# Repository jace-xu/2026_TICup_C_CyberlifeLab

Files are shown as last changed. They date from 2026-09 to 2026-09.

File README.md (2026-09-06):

# 2026 TI Cup — Wireless Digital Key System

A digital key and smart lock prototype developed for Problem C of the 2026 TI Cup Undergraduate Electronic Design Contest (Guangdong Division). The system combines UWB wireless communication with LiDAR localization to identify an authorized key, track its position, and trigger welcome alerts, automatic unlocking, and locking when the key leaves the designated area.

## Highlights

- **Key identification:** An STM32F103-based wireless key transmits a configurable 4-bit ID for matching against the lock's configured ID.
- **Position tracking:** A Raspberry Pi 5 running ROS 2 processes RPLIDAR C1 scans using background modeling, target extraction, and clustering, then sends distance and bearing to an STM32H723 over USB serial.
- **Sensor fusion:** Supports UWB-only and UWB/LiDAR modes, with coordinate alignment, outlier rejection, and Kalman filtering to reduce positioning drift.
- **Embedded control:** STM32H723 firmware handles UWB UART and Raspberry Pi USB CDC communication, matches key IDs, and drives proximity-based status logic, the serial display, RGB LEDs, and buzzer.
- **Integrated hardware:** A display, lights, and buzzer provide status feedback, with a custom 3D-printed enclosure and mounting structure.

**Tech stack:** STM32 · Embedded C · STM32 HAL · Keil MDK · Raspberry Pi 5 · ROS 2 · Python · UWB · LiDAR · Kalman Filter · SolidWorks

## Prototypes

<p align="center">
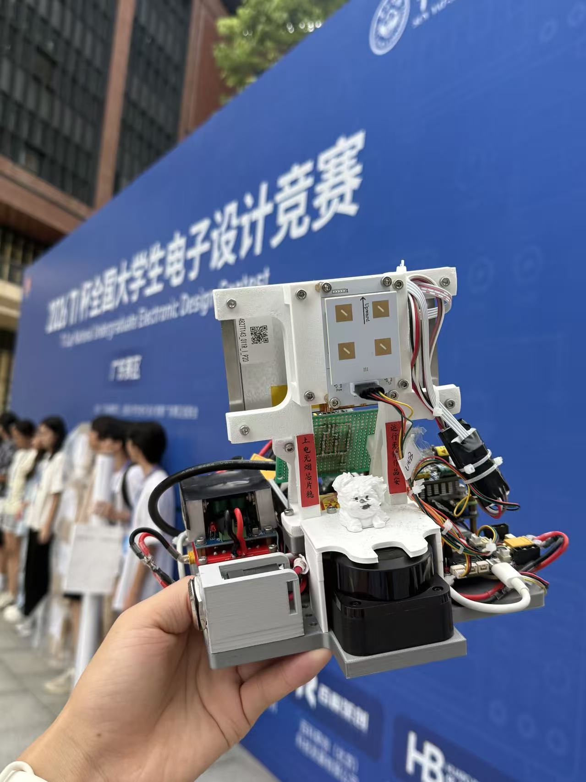
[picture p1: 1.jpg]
Smart lock prototype at the competition venue
  
</p>

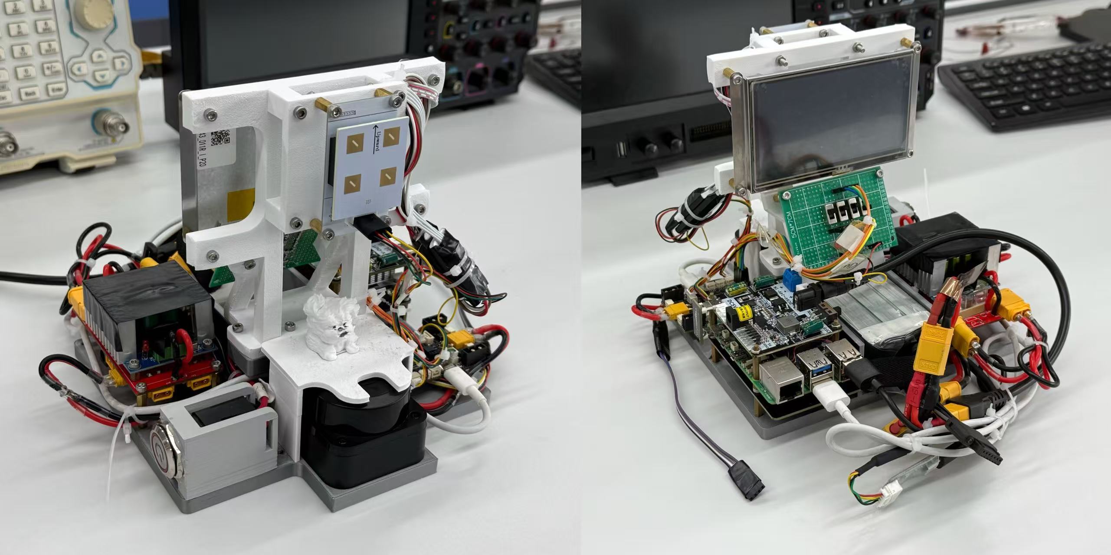
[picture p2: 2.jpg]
Front and rear views of the smart lock


### Digital Key

<p align="center">
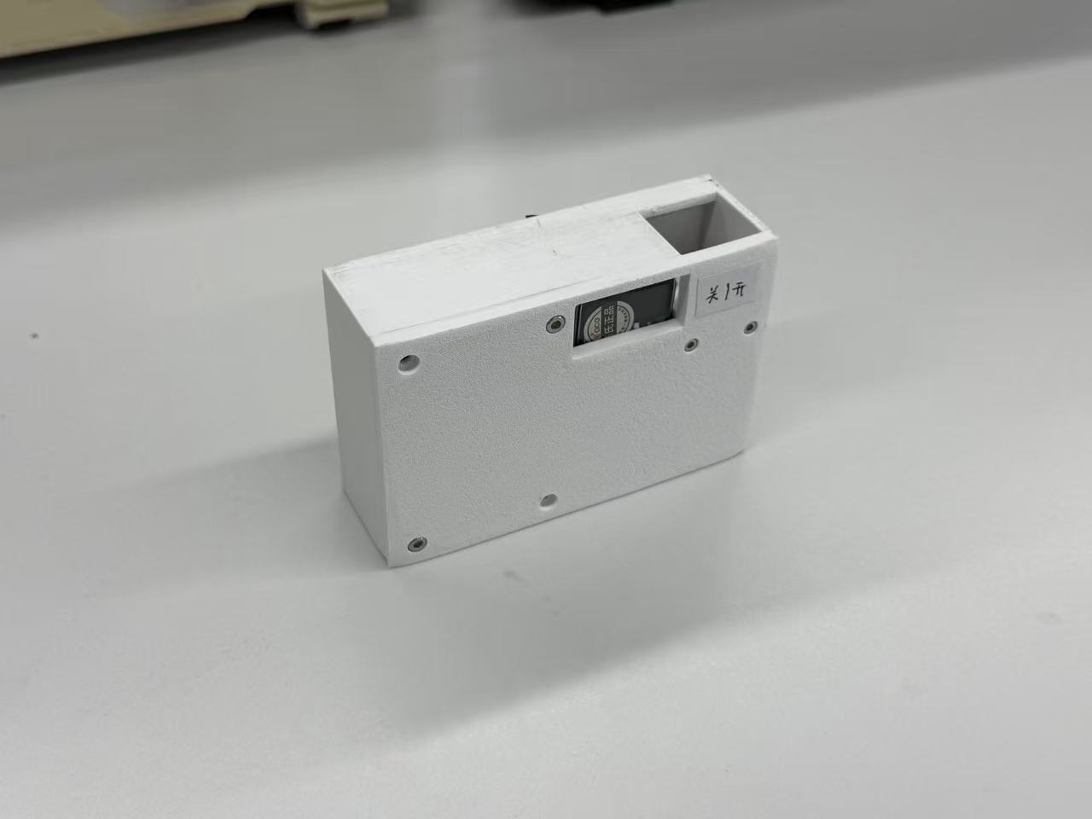
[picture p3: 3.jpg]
Wireless digital key prototype
  
</p>

## Our Team

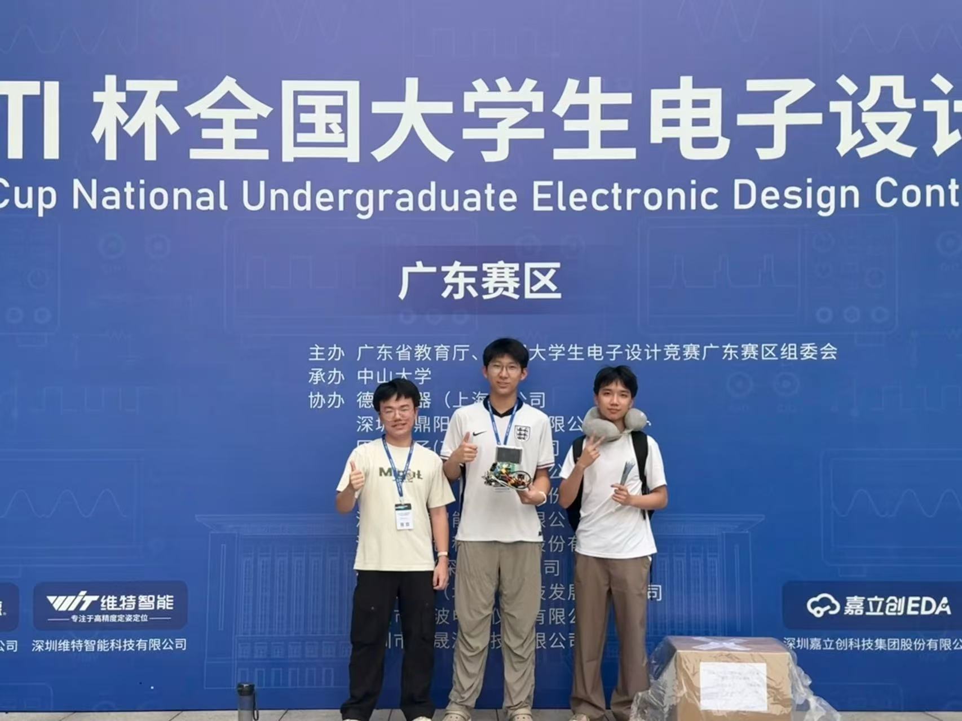
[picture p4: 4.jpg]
Our team at the competition


## Repository

- [`Electronics_STM32H7/`](Electronics_STM32H7/) — STM32H723 smart lock firmware, including peripheral drivers, communication, and status control, with STM32CubeMX and Keil MDK project files.

- [`Pi5_lidar/`](Pi5_lidar/) — ROS 2 workspace for LiDAR localization and serial communication.
- [`Structure/`](Structure/) — SolidWorks models and STEP files for the mechanical assembly.
- [`Report.pdf`](Report.pdf) — Project report with system design and test results (Chinese).

## License

Original project code is licensed under the [GNU General Public License v3.0](LICENSE) (SPDX: `GPL-3.0-only`). Third-party components retain their respective licenses and copyright notices.

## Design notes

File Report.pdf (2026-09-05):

# 2026 年全国大学生电子设计竞赛 广东赛区竞赛

## 基于无线通信的数字钥匙实验系统系统（C 题）

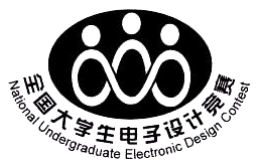
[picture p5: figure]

# 2026 年 8 月 1 日

I

摘 要

针对数字钥匙系统在身份认证、复杂环境稳定定位方面的要求，本设计研制

了一套基于无线通信的数字钥匙实验系统。系统由数字钥匙和智能门锁两部分组

成。数字钥匙端以 STM32F103C8T6 为控制核心，由开关、电池、UWB 无线模块和

降压模块，实现一键启动及 4 位身份 ID 持续发送。智能门锁端由 UWB 基站、激

光雷达、树莓派、STM32H723、串口屏、四位拨码开关和声光装置组成。UWB 基

站接收钥匙 ID 并输出距离和方位角；树莓派完成雷达背景建模、目标提取、聚

类跟踪和位置计算，通过 USB 虚拟串口将结果发送至 STM32H723。系统支持纯 UWB

和 UWB/激光雷达融合两种模式。融合模式下，H723 对两路观测进行坐标统一、

时间匹配和异常值剔除，并通过卡尔曼滤波获得更准确的钥匙位置，解决了纯

UWB 定位的漂移问题。控制系统比较接收 ID 与拨码设定 ID，根据径向距离完成

感应区、迎宾区和开锁区判决，并显示身份、位置、区域和门锁状态，控制灯光、

蜂鸣器及开闭锁指示灯。测试结果表明，系统可实现身份验证、迎宾提示、自动

开锁、离区闭锁和 ID 修改识别，满足题目要求。

关键词：数字钥匙；UWB；激光雷达；卡尔曼滤波；多传感器融合

目录

## 一、系统方案

1、主控制器件的论证与选择

2、定位方案的论证与选择
3、电源方案的论证与选择

## 二、系统理论分析与计算

1、UWB 身份认证与定位原理

2、激光雷达目标定位

3、UWB 与激光雷达融合定位

## 三、电路与程序设计

1、电路设计

2、程序设计

## 四、测试方案与测试结果

1、测试方案

2、测试条件与仪器

3、测试结果及分析

## 五、参考文献

## 基于无线通信的数字钥匙实验系统（C 题）

## 一、系统方案

本系统由数字钥匙和智能门锁两部分组成，主要包括数字钥匙控制模块、UWB 无线

通信模块、激光雷达定位模块、主控制与数据融合模块、人机交互与执行模块以及电源

模块。数字钥匙持续发送身份 ID 信息，智能门锁通过 UWB 和激光雷达获取数字钥匙的

位置，并完成身份验证、定位模式切换、区域判决、状态显示及开闭锁控制。下面分别

对系统中的主要方案进行论证与选择。

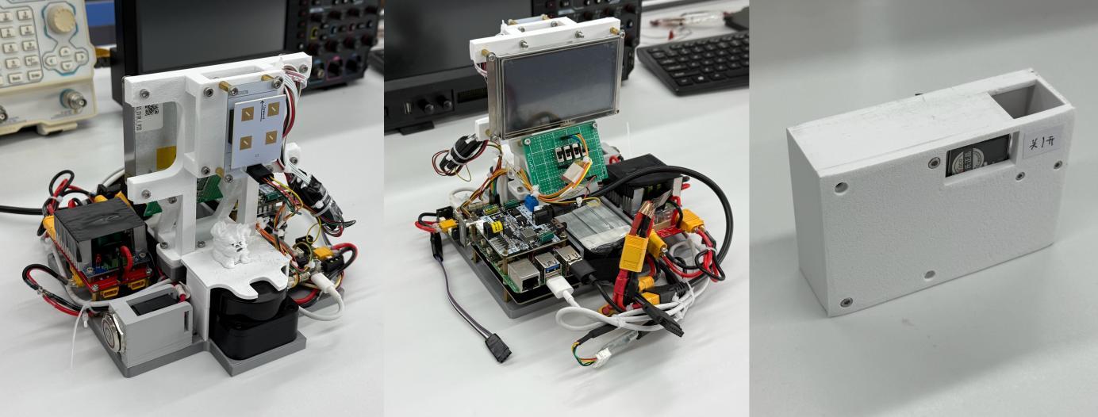
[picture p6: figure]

图 1.1 团队设计的基于无线通信的数字钥匙实验系统，自左到右分别为智能门锁正面，

智能门锁背面，数字钥匙

1、主控制器件的论证与选择

方案一：单片机独立控制。

单片机实时性好、接口丰富，可完成数据接收和设备控制，但运算及存储能力有限，

难以实时处理激光雷达点云数据，因此不适合作为整体控制方案。

方案二：树莓派独立控制。

树莓派运算能力强，可实现雷达驱动和定位算法，但 GPIO 实时性和抗干扰能力较弱，

直接控制门锁、声光装置等设备，可靠性不足。

方案三：树莓派与 STM32H723 协同控制。

树莓派负责雷达数据处理和位置计算，并将结果发送至 STM32H723；STM32H723 负责

接收 UWB 数据，完成数据融合、身份验证、区域判决及门锁和声光控制。数字钥匙采用

STM32F103C8T6 发送身份 ID。

综合比较，本系统选择方案三。该方案兼顾树莓派的运算能力和单片机的实时控制

性能，可提高系统的实时性、可靠性和可维护性。

2、定位方案的论证与选择

方案一：采用纯 UWB 定位。

UWB 可同时传输身份 ID 并输出距离和方位角，具有结构简单、数据链路短等优点。

但室内反射和多径效应容易造成测量波动，影响区域边界判决的稳定性。

方案二：采用纯激光雷达定位。

激光雷达测距和测角精度较高，不受无线电多径影响。树莓派可通过背景差分、目

标聚类和连续跟踪提取钥匙靶标，但雷达无法独立识别身份 ID，且容易受到靶标姿态、

反射特性和短时遮挡影响。

方案三：UWB 与激光雷达融合定位。

该方案使用卡尔曼滤波融合 UWB 的身份与位置数据和激光雷达的几何定位结果。当

UWB 受到多径干扰时提高雷达权重，当雷达短时丢点时利用 UWB 维持定位，从而提高测

量精度和稳定性。

综合比较，本系统采用双模式方案：纯 UWB 模式用于独立定位和备用运行，UWB/激

光雷达融合模式作为主要工作模式。

3、电源方案的论证与选择

方案一：分散式供电。

各模块分别使用对应电压的电池，或由一块 24V 电池配合多个独立 DC-DC 模块供电。

该方案配置灵活、便于单独调试，但电池和稳压模块数量较多，存在接线复杂、成本增

加、体积较大及电磁干扰难以统一控制等问题，不利于系统集成。

方案二：集中式稳压分电板供电。

智能门锁端采用一块 24V 电池，将输入保护、降压和多路分配电路集中在自制 PCB

分电板上，输出 24V、12V 和 5V 等电压；数字钥匙端采用一块 12V 电池，经板载降压模

块供电。该方案接线清晰、结构紧凑，便于统一完成滤波、接地、散热和故障排查。

综合比较，本系统选择方案二，以提高供电系统的集成度、稳定性和可靠性。 二、系统理论分析与计算

1、UWB 身份认证与定位原理

本系统采用 ALX-AOA-FIT 模块，工作于单基站、单信标模式。基站基于单芯片 UWB

方案，片上集成 32 位 MCU，通过 4 天线阵列实现 AOA 测量；信标安装于数字钥匙端，持

续发送 UWB 信号。

UWB 测距基于双边双向飞行时间原理，基站与信标之间交替收发时间戳，消除两

Δ =

4 − 1 − 3 − 2

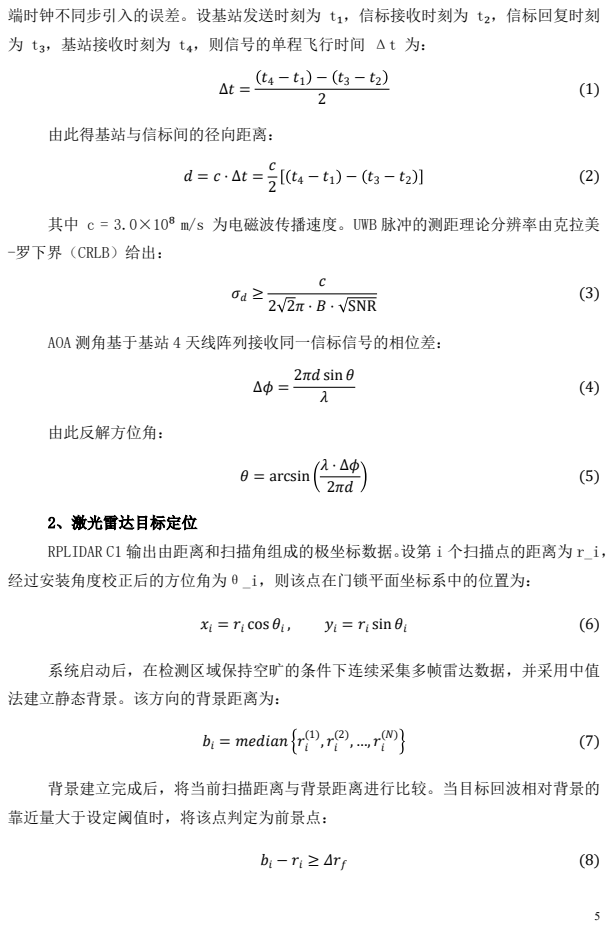
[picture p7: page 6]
端时钟不同步引入的误差。设基站发送时刻为 t₁，信标接收时刻为 t₂，信标回复时刻; 为 t₃，基站接收时刻为 t₄，则信号的单程飞行时间 Δt 为： 2; 由此得基站与信标间的径向距离：  =  ⋅ Δ =;  2 2 ⋅  ⋅ SNR; 2 sin  ; 由此反解方位角：;  = arcsin;  =  cos ; ,  =  sin 

其中 c = 3.0×10⁸ m/s 为电磁波传播速度。UWB 脉冲的测距理论分辨率由克拉美

-罗下界（CRLB）给出：

AOA 测角基于基站 4 天线阵列接收同一信标信号的相位差：

2、激光雷达目标定位
RPLIDAR C1 输出由距离和扫描角组成的极坐标数据。设第 i 个扫描点的距离为 r_i，
经过安装角度校正后的方位角为θ_i，则该点在门锁平面坐标系中的位置为：

系统启动后，在检测区域保持空旷的条件下连续采集多帧雷达数据，并采用中值
法建立静态背景。该方向的背景距离为：

背景建立完成后，将当前扫描距离与背景距离进行比较。当目标回波相对背景的
靠近量大于设定阈值时，将该点判定为前景点：

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

## 三、电路与程序设计

1、电路设计

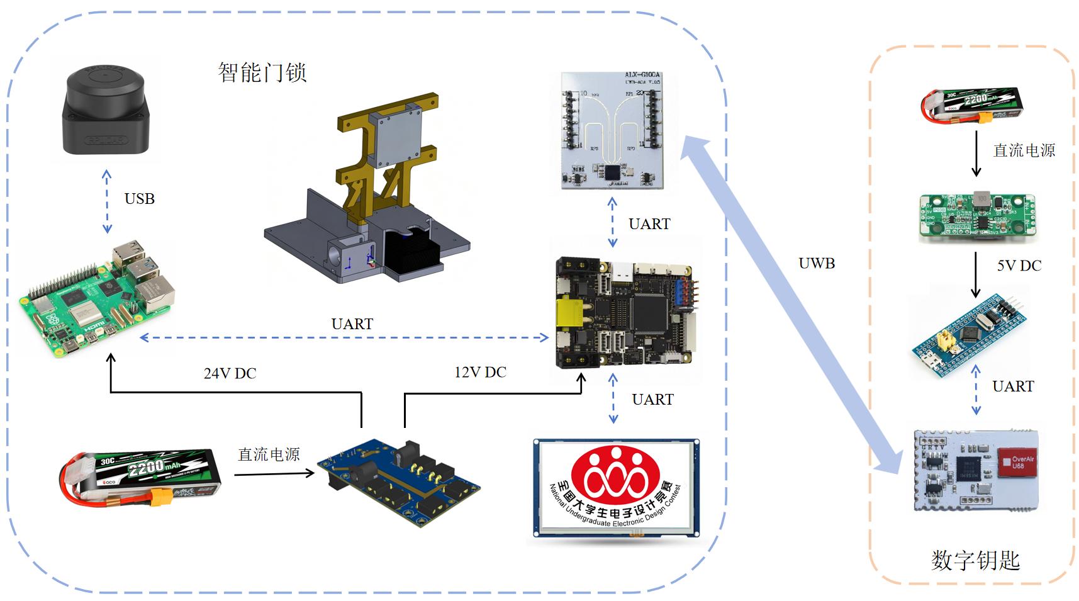
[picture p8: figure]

图 3.1 系统电路架构图

1.1 数字钥匙子系统的电路设计

数字钥匙子系统由 STM32F103C8T6、DW3000 PDOA 从机模块和电源电路组成。系统上

电后，单片机配置 UWB 模块并写入身份 ID，由模块周期性广播定位信标，供门锁端解算

钥匙的距离和方位角。12 V 锂电池经降压后为各模块供电，保证系统稳定运行。

1.2 智能门锁子系统的电路设计

本系统采用树莓派与 STM32H7 组成双主控架构。24 V 电源经降压后为两块主控板供

电，树莓派通过 USB 为激光雷达供电。树莓派负责雷达数据处理、人员检测和定位计算，

并通过 USB 虚拟串口与 STM32H7 通信；STM32H7 负责接收定位结果、执行实时控制以及

管理各类外设。

UWB 模块用于获取数字钥匙的身份 ID、距离和方位角，激光雷达用于辅助人员检测

和定位。STM32H7 将钥匙 ID 与拨码开关设定值进行比对，并根据身份和位置控制门锁状

态；串口屏显示身份及定位信息，开锁和闭锁 LED 用于指示门锁状态。系统采用默认闭

锁原则，仅在身份验证通过且钥匙进入开锁区域时执行开锁。

2、程序设计
2.1 数字钥匙子系统的程序设计

数字钥匙端采用 STM32F103C8T6 作为控制器，外部开关直接控制数字钥匙的电源通

断。开关闭合后，控制器和 UWB 无线模块上电，程序依次完成系统时钟、GPIO、串口及

无线模块初始化，并装载数字钥匙预设的 4 位身份 ID。

初始化完成后，程序立即进入循环发送状态。STM32F103C8T6 将身份 ID 按照规定的

数据格式进行封装，并控制 UWB 无线模块按照固定时间间隔持续发送。门锁端 UWB 基站

接收到无线信号后，可获得数字钥匙的标签 ID 以及相应的位置观测数据。

在运行过程中，程序持续检查 UWB 无线模块的工作状态。若某次数据发送未正常完

成，则清除当前发送状态，并在下一发送周期重新传输，从而提高无线通信的连续性和

可靠性。只要电源开关保持闭合，数字钥匙就会持续发送身份 ID；用户断开电源开关后，

数字钥匙停止工作。
2.2 智能门锁子系统的程序设计

2.2.1 树莓派程序设计

树莓派运行 Ubuntu 24.04 和 ROS 2 Jazzy 系统。程序启动后首先检查激光雷达和

STM32H723 的串口设备是否连接正常，随后启动激光雷达驱动、数字钥匙定位节点和串

口通信节点。

定位节点启动后的前两秒保持检测区域空旷，连续采集多帧雷达数据，并计算各扫

描方向的中值，从而建立静态背景。背景建立完成后，程序持续订阅激光雷达扫描数据，

只保留智能门锁正前方±47°范围内的有效回波。

对于每帧雷达数据，程序首先完成安装角度校正和距离范围筛选，再通过背景差分

提取新进入检测区域的前景点。随后根据相邻点之间的空间距离和角度间隔进行聚类，

并依据数字钥匙定位靶标的尺寸筛除人体、支架等不符合要求的点簇。当检测区域内存

在多个候选目标时，程序选择距离智能门锁最近的有效目标。关于筛选目标的原理，在

前文理论分析处已经得到计算。程序根据目标中心坐标计算数字钥匙相对于门锁圆柱体

边界的径向距离和方位角，并将检测标志、径向距离和方位角封装为固定长度的数据帧，

通过 USB 虚拟串口发送至 STM32H723。

2.2.2 单片机程序设计

STM32H723 是智能门锁的主控制器，主要负责 UWB 和雷达数据接收、工作模式切换、

身份验证、卡尔曼融合、区域判决以及显示和执行器控制。

系统上电后，STM32H723 完成 GPIO、UART、USB 虚拟串口、定时器、SPI 和 PWM 等外

设初始化。UWB 基站通过 UART 发送数字钥匙 ID、距离和方位角，树莓派通过 USB 虚拟

串口发送雷达检测标志、距离和方位角。单片机对接收到的数据进行格式检查，数据错

误或长时间未更新时，将对应观测标记为无效。

程序周期性读取四位拨码开关，并将接收 ID 与设定 ID 进行比较。不一致时，系统

保持闭锁并显示验证失败；一致时，根据模式切换按键选择纯 UWB 模式或融合定位模式。

纯 UWB 模式直接使用 UWB 输出的距离和方位角。融合模式首先将 UWB 和雷达数据转

换到统一坐标系，剔除异常观测，再利用卡尔曼滤波获得融合位置。当某一路数据暂时

失效时，系统使用另一路有效数据继续定位；两路数据均无效时，系统输出未检测状态

并保持闭锁。

身份验证和定位均有效时，单片机根据最终距离判断数字钥匙位于感应区、迎宾区

或开锁区，并控制串口屏、灯光、蜂鸣器以及开闭锁指示灯。程序采用连续帧确认和滞

回判决，防止距离在 1 m 和 2 m 边界附近波动时门锁状态反复切换。

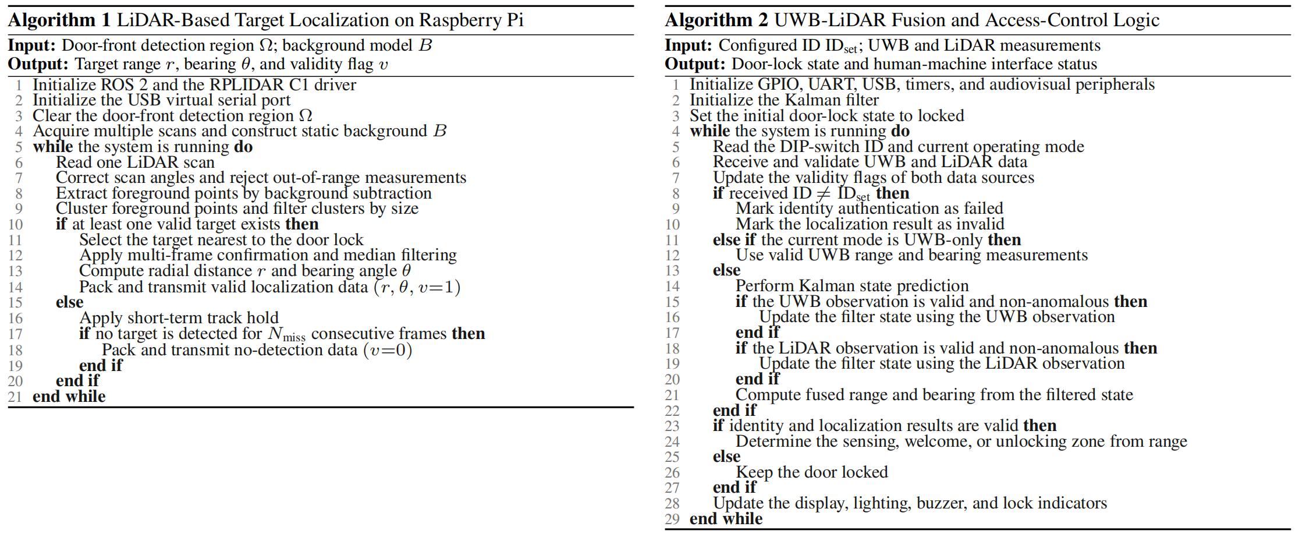
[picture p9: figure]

图 3.2 树莓派和单片机程序的伪代码

## 四、测试方案与测试结果

1、测试方案

在 0.5 m、1.5 m 和 2.5 m 三个距离下，分别设置−40°、−20°、0°、+20°和+40°

五个方位角，共 15 个测试点，每点重复测量 20 次。同步记录 UWB、激光雷达和融合定

位输出的距离及角度，并计算平均误差、均方根误差和最大误差。此外，在 1 m 开锁边

界和 2 m 迎宾边界进行进入、离开测试，验证系统的区域判定性能。

2、测试条件与仪器

测试在室内开阔、无遮挡环境下进行，各定位模块位置保持固定。使用激光测距仪

或钢卷尺标定实际距离，使用角度尺和地面标线确定方位角。主要仪器包括 UWB 模块、

二维激光雷达、数字钥匙、主控板、稳压电源和上位机。

3、测试结果及分析

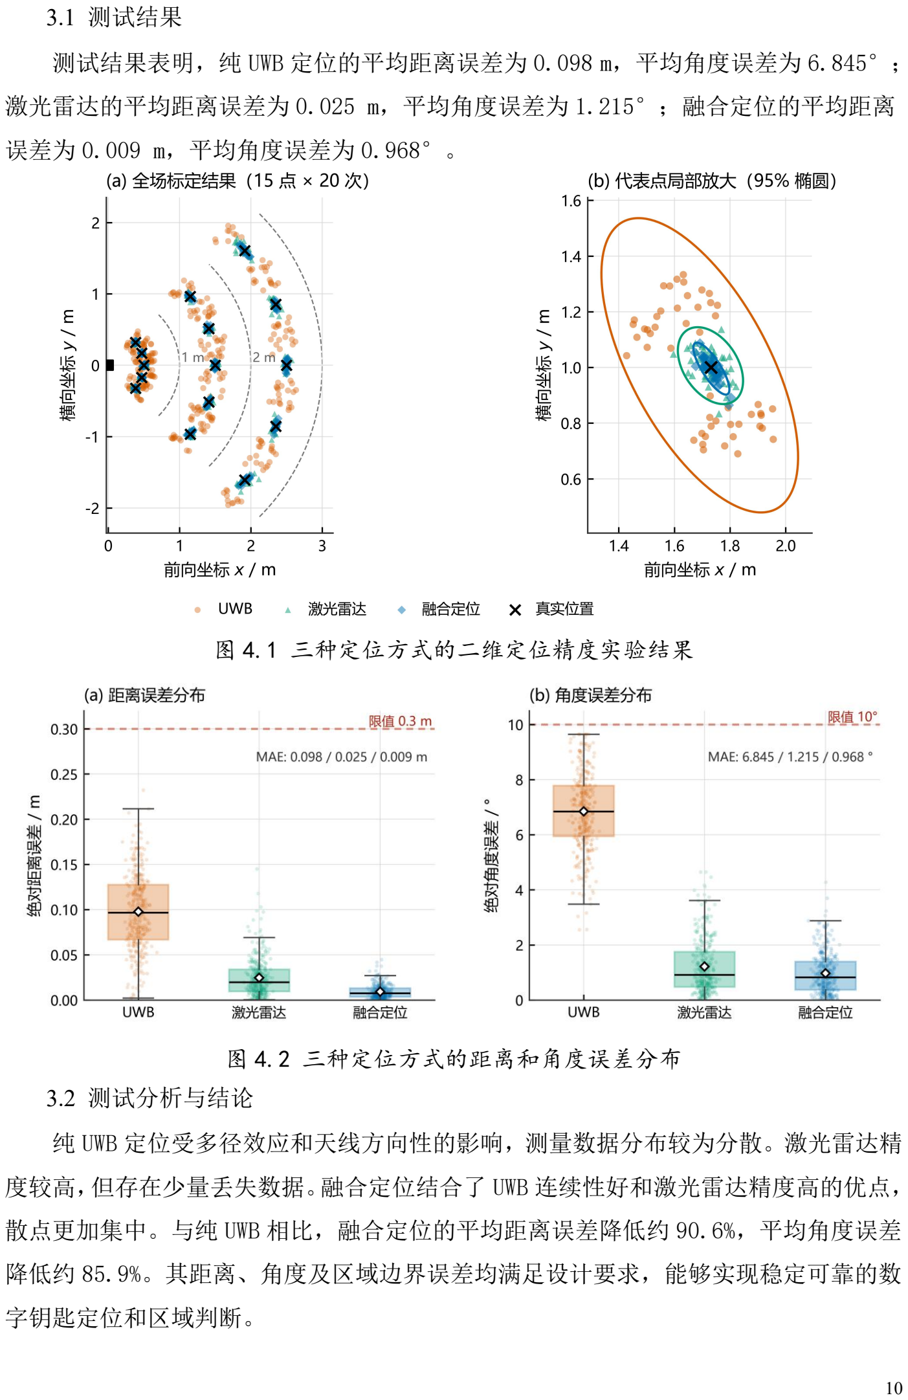
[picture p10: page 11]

3.1 测试结果

测试结果表明，纯 UWB 定位的平均距离误差为 0.098 m，平均角度误差为 6.845°；

激光雷达的平均距离误差为 0.025 m，平均角度误差为 1.215°；融合定位的平均距离

误差为 0.009 m，平均角度误差为 0.968°。

图 4.1 三种定位方式的二维定位精度实验结果

图 4.2 三种定位方式的距离和角度误差分布
3.2 测试分析与结论

纯 UWB 定位受多径效应和天线方向性的影响，测量数据分布较为分散。激光雷达精

度较高，但存在少量丢失数据。融合定位结合了 UWB 连续性好和激光雷达精度高的优点，

散点更加集中。与纯 UWB 相比，融合定位的平均距离误差降低约 90.6%，平均角度误差

降低约 85.9%。其距离、角度及区域边界误差均满足设计要求，能够实现稳定可靠的数

字钥匙定位和区域判断。

## 五、参考文献

[1] 柳景斌。室内高精度定位技术总结与展望 [J]. 武汉大学学报 (信息科学版), 2022. DOI:
10.13203/j.whugis20220029. [2] Sang C L, Adams M, Hesse M, et al. Numerical and Experimental Evaluation of Error Estimation

for Two-Way Ranging Methods[J]. Sensors, 2019, 19(3): 616.DOI: 10.3390/s19030616
[3] Wu J, Xiong Y, Li W, et al. Adaptive Kalman Filter-Based UWB Location Tracking with Optimized DS-TWR in Workshop Non-Line-of-Sight Environments[J]. Sensors, 2025, 25(24): 7682. DOI: 10.3390/s25247682
[4] 郑洪江，夏宝华，韩松源，等。数字钥匙非可视测距研究与实现 [J]. 汽车工程，2026, 48 (6):
1294-1303.DOI: 10.19562/j.chinasae.qcgc.2026.06.007
[5] 谭浩强. C 语言程序设计 [M]. 北京：清华大学出版社，2012. [6] Li T, Wang Y, Zhang H. UWB-LiDAR Tightly Coupled Indoor Positioning System for Mobile

Robots[C]//Proceedings of the 2024 6th International Conference on Robotics and Intelligent Systems. New York: ACM, 2024: 127-134. DOI: 10.1145/3711129.3711
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

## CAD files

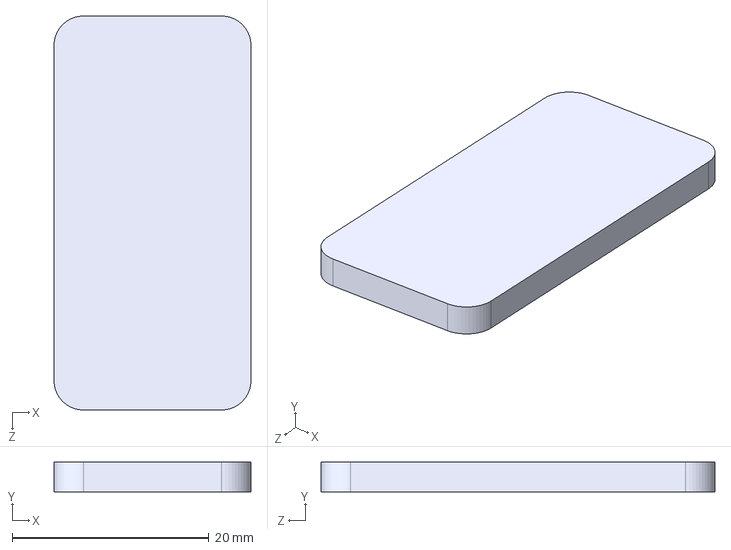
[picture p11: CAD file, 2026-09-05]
Structure/基站建模/杜邦线固定板.STEP
20.0 x 3.00 x 40.0 mm

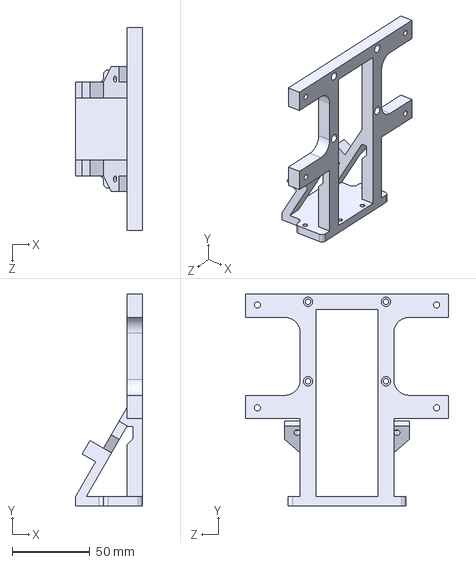
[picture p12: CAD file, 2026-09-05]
Structure/基站建模/基站支架.STEP
43.0 x 136.0 x 130.0 mm

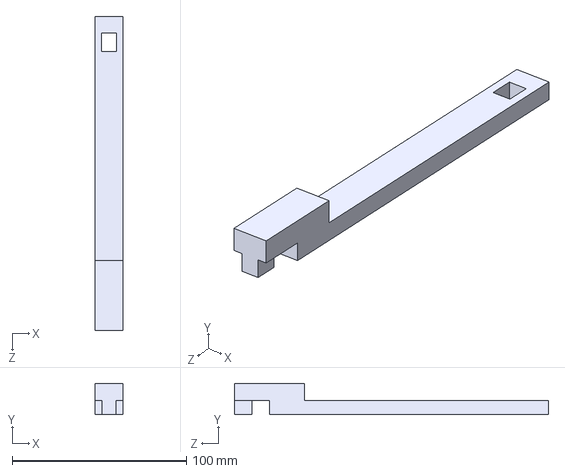
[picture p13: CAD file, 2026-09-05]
Structure/放置基站模具/扩展棍.STEP
16.0 x 18.0 x 180.0 mm

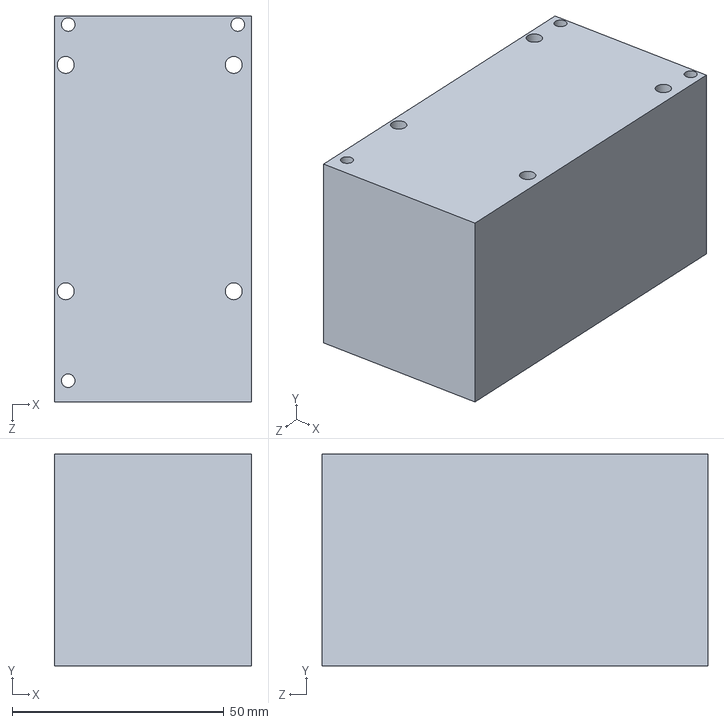
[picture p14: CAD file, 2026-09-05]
Structure/基站建模/降压板.SLDPRT
46.5 x 50.0 x 91.0 mm

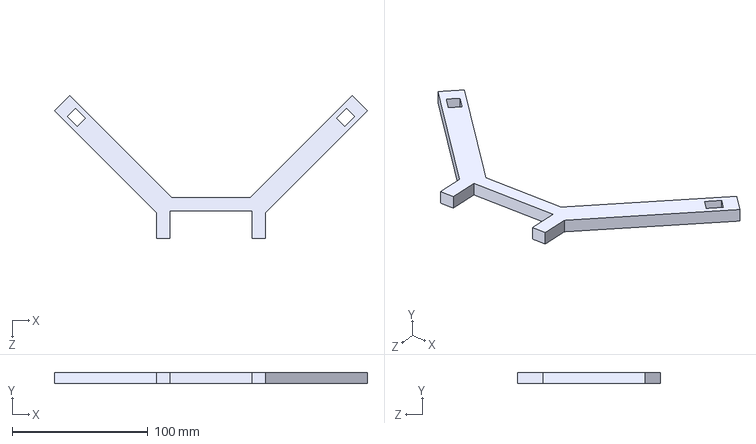
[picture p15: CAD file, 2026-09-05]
Structure/放置基站模具/中心板.STEP
230.5 x 8.00 x 105.3 mm

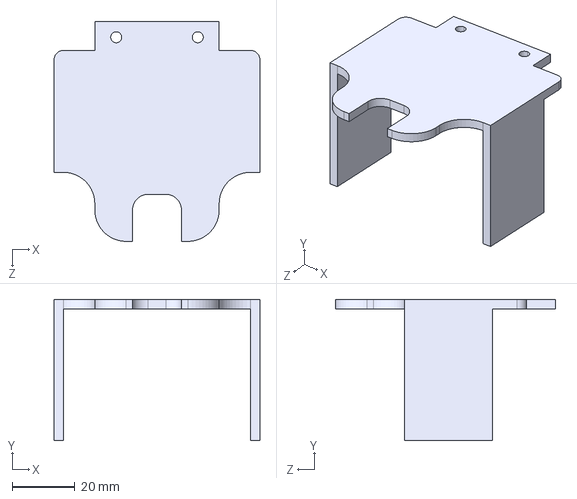
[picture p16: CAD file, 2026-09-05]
Structure/基站建模/雷达罩.STEP
65.6 x 45.0 x 70.0 mm

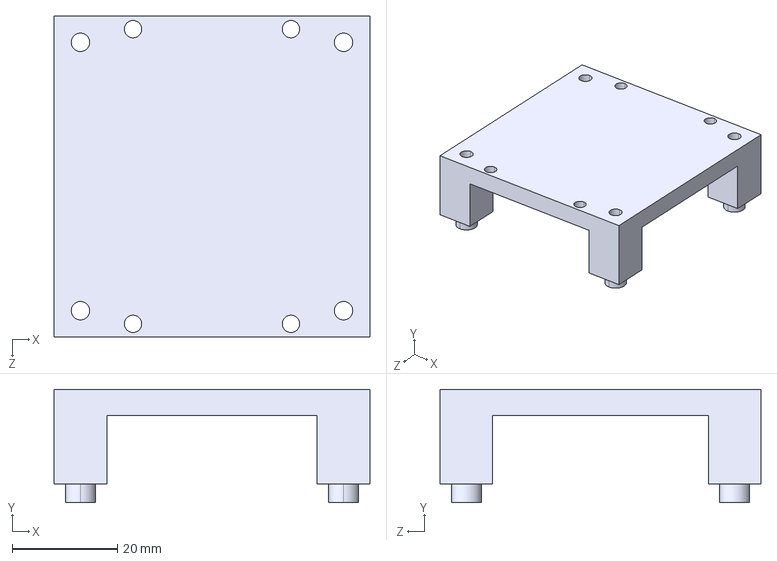
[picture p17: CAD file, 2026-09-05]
Structure/基站建模/基站底板.STEP
60.0 x 21.5 x 61.0 mm

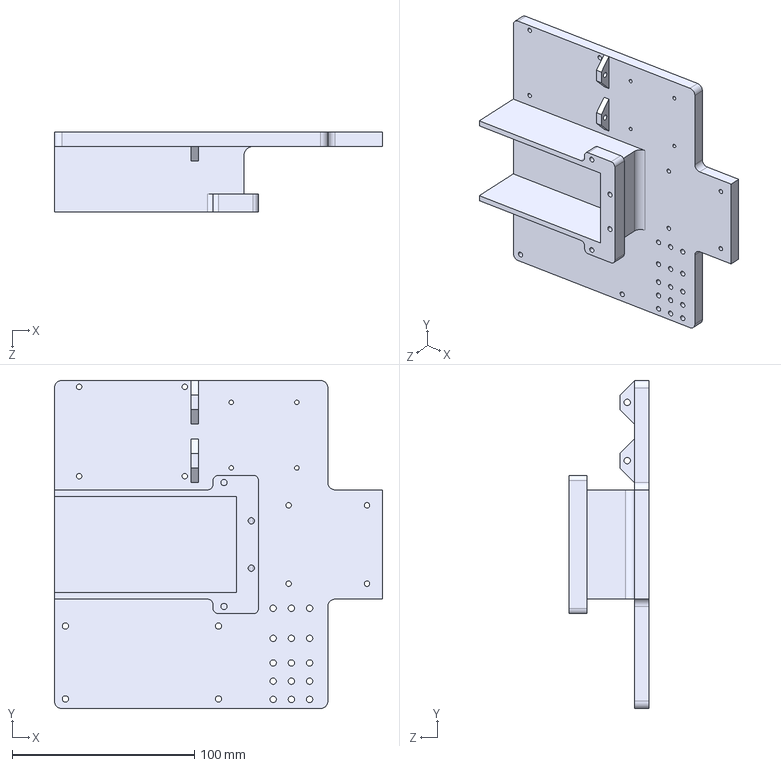
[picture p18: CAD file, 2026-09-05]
Structure/基站建模/雷达底座.STEP
180.0 x 180.0 x 44.0 mm

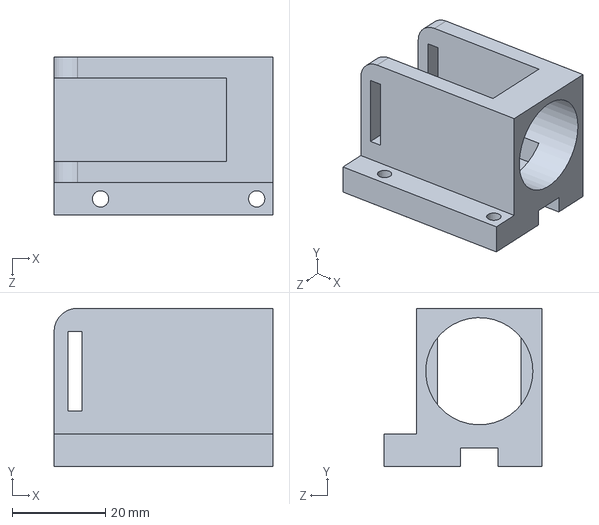
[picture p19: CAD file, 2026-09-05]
Structure/基站建模/开关支架.SLDPRT
47.0 x 34.0 x 34.0 mm

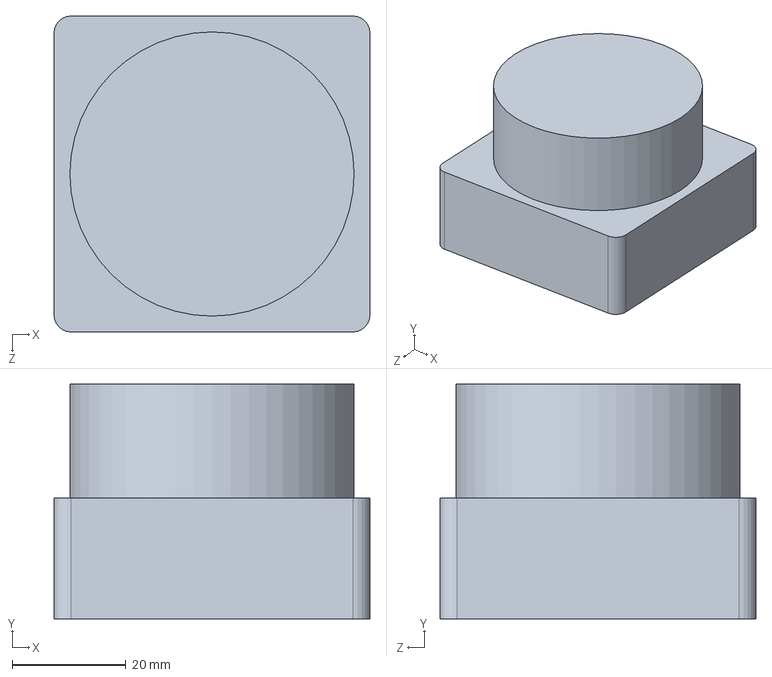
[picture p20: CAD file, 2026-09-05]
Structure/基站建模/c1雷达.SLDPRT
55.6 x 41.3 x 55.6 mm

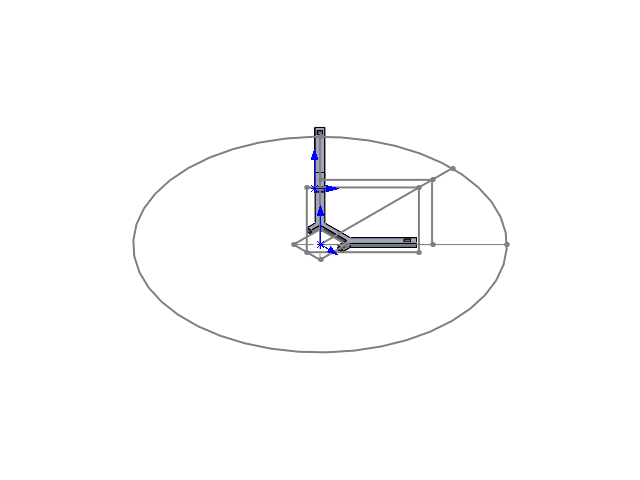
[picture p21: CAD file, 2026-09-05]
Structure/放置基站模具/模具装配体.SLDASM
中心板
扩展棍

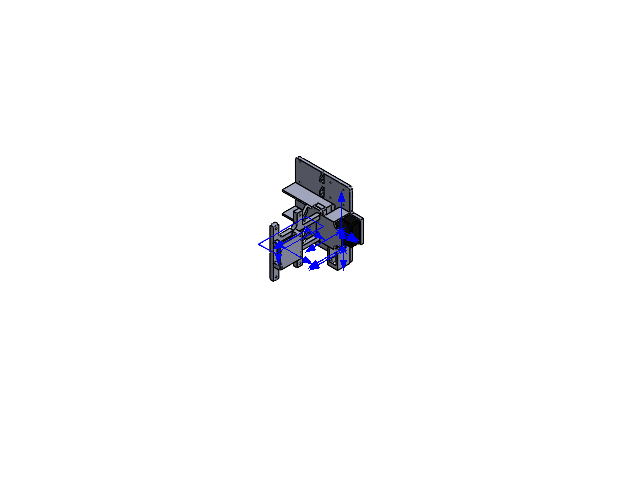
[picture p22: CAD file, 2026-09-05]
Structure/基站建模/基站装配体.SLDASM
雷达底座
c1雷达
基站支架
基站底板
开关支架
雷达罩

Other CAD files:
Structure/基站建模/基站底板.SLDPRT
Structure/基站建模/基站支架.SLDPRT
Structure/基站建模/杜邦线固定板.SLDPRT
Structure/基站建模/雷达底座.SLDPRT
Structure/基站建模/雷达罩.SLDPRT
Structure/放置基站模具/中心板.SLDPRT
Structure/放置基站模具/扩展棍.SLDPRT

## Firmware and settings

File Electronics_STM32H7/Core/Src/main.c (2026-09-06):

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
/* Includes ------------------------------------------------------------------*/
#include "main.h"
#include "spi.h"
#include "tim.h"
#include "usart.h"
#include "usb_device.h"
#include "gpio.h"

/* USER CODE BEGIN Includes */
#include "ws2812.h"
#include "buzzer_driver.h"
/* USER CODE END Includes */


/* USER CODE BEGIN PV */
volatile uint8_t id_receive = 0xFF;
uint8_t id_set = 0;
volatile data_packet_t data_packet = {0};
volatile key_data_t key_data = {0};
volatile uint8_t use_raspi = 1;  /* 1=树莓派数据(USB CDC), 0=UWB模块数据(UART10) */
volatile uint8_t raspi_first_beep = 0;  /* 0=等待首次数据, 1=待蜂鸣, 2=已完成 */
extern uint8_t rx_buffer[];
extern uint8_t rx_buffer2[];

/* WS2812 灯控标志（ISR 写，主循环读） */
extern volatile uint8_t ws2812_update;
extern volatile uint8_t ws2812_r;
extern volatile uint8_t ws2812_g;
extern volatile uint8_t ws2812_b;
extern volatile uint8_t ws2812_last_r;
extern volatile uint8_t ws2812_last_g;
extern volatile uint8_t ws2812_last_b;
/* USER CODE END PV */

void SystemClock_Config(void);
static void MPU_Config(void);
/**
  * @brief  The application entry point.
  * @retval int
  */
int main(void)
{

  /* MPU Configuration--------------------------------------------------------*/
  MPU_Config();

  /* MCU Configuration--------------------------------------------------------*/

  /* Reset of all peripherals, Initializes the Flash interface and the Systick. */
  HAL_Init();

  /* Configure the system clock */
  SystemClock_Config();

  /* Initialize all configured peripherals */
  MX_GPIO_Init();
  MX_TIM1_Init();
  MX_UART7_Init();
  MX_USART10_UART_Init();
  MX_SPI6_Init();
  MX_TIM12_Init();
  MX_USB_DEVICE_Init();
  /* USER CODE BEGIN 2 */
	/* 清空 USART10 RX 残留，避免字节错位导致永久偏移 */
	/* 空闲帧分包接收 UWB 变长数据包（0x2001=37B / 0x2002=16B） */
	HAL_UARTEx_ReceiveToIdle_IT(&huart10, rx_buffer, 64);
	// 开启TIM1 更新中断
	HAL_TIM_Base_Start_IT(&htim1);
  // 开启蜂鸣器
  HAL_TIM_PWM_Start(&htim12, TIM_CHANNEL_2);
  /* 上电测试音：响 300ms 验证蜂鸣器硬件正常 */
  Buzzer_Play(BUZZER_FREQ_C4, 100);
  HAL_Delay(300);
  Buzzer_Stop();
  /* 初始化 flag 引脚：默认树莓派模式 → 高电平 */
  HAL_GPIO_WritePin(flag_GPIO_Port, flag_Pin, GPIO_PIN_SET);
  /* 使能 botton 按键的 EXTI 中断（PA15 → EXTI15_10） */
  HAL_NVIC_SetPriority(EXTI15_10_IRQn, 2, 0);
  HAL_NVIC_EnableIRQ(EXTI15_10_IRQn);
  HAL_GPIO_WritePin(en_GPIO_Port,en_Pin,GPIO_PIN_SET);
  /* USER CODE END 2 */

  /* Infinite loop */
  /* USER CODE BEGIN WHILE */
  while (1)
  {
    /* USER CODE END WHILE */

    /* USER CODE BEGIN 3 */
    /* ═══════════════════════════════════════════════════════════════
     * 测试模式：手动注入数据，不依赖串口/UWB
     * 每 5 秒自动轮转一个场景，测试 LED + 蜂鸣器动作
     * 测试完成后将 #if 1 改为 #if 0 即可关闭
     * ═══════════════════════════════════════════════════════════════ */
#if 0
    {
        static uint8_t  test_phase = 0;
        static uint32_t last_tick  = 0;
        uint32_t now = HAL_GetTick();

        if (now - last_tick >= 1000)   /* 每 1 秒切换场景 */
        {
            last_tick = now;

            switch (test_phase)
            {
            case 0:  /* 无钥匙 → LED 灭 */
                id_receive             = 0xFF;
                data_packet.if_detect  = 0;
                data_packet.distance   = 0.0f;
                data_packet.angle      = 0.0f;
                break;

            case 1:  /* 感应区 ≥200cm → 蓝灯 */
                id_receive             = id_set;
                data_packet.if_detect  = 1;
                data_packet.distance   = 250.0f;
                data_packet.angle      = 45.0f;
                break;

            case 2:  /* 迎宾区 100~200cm → 黄灯 + 升调（感应→迎宾） */
                id_receive             = id_set;
                data_packet.if_detect  = 1;
                data_packet.distance   = 150.0f;
                data_packet.angle      = 30.0f;
                break;

            case 3:  /* 开锁区 ≤100cm → 绿灯 */
                id_receive             = id_set;
                data_packet.if_detect  = 1;
                data_packet.distance   = 50.0f;
                data_packet.angle      = 15.0f;
                break;

            case 4:  /* 迎宾区 → 黄灯 */
                id_receive             = id_set;
                data_packet.if_detect  = 1;
                data_packet.distance   = 150.0f;
                data_packet.angle      = 30.0f;
                break;

            case 5:  /* 感应区 → 蓝灯 + 降调（迎宾→感应） */
                id_receive             = id_set;
                data_packet.if_detect  = 1;
                data_packet.distance   = 250.0f;
                data_packet.angle      = 45.0f;
                break;

            case 6:  /* ID 不匹配 → 红灯 */
                {
                    uint8_t fake_id = (id_set == 0) ? 1 : 0; /* 故意错 */
                    id_receive             = fake_id;
                    data_packet.if_detect  = 1;
                    data_packet.distance   = 100.0f;
                    data_packet.angle      = 0.0f;
                }
                break;
            }

            test_phase++;
            if (test_phase > 6) { test_phase = 0; }
        }
    }
#endif

    /* 首次收到树莓派有效串口数据 → 蜂鸣器确认（高音短促，与开机自检低音区分） */
    if (raspi_first_beep == 1)
    {
        raspi_first_beep = 2;
        Buzzer_Play(BUZZER_FREQ_E6, 100);
        HAL_Delay(150);
        Buzzer_Stop();
    }

    /* WS2812 灯控：ISR 设标志，主循环执行 SPI 传输 */
    if (ws2812_update)
    {
        ws2812_update = 0;
        WS2812_Ctrl(ws2812_r, ws2812_g, ws2812_b);
        /* 记录本次实际写入的 RGB，供 ISR 判断是否需要下次刷新 */
        ws2812_last_r = ws2812_r;
        ws2812_last_g = ws2812_g;
        ws2812_last_b = ws2812_b;
    }
  }
  /* USER CODE END 3 */
}

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
 /* MPU Configuration */

void MPU_Config(void)
{
  MPU_Region_InitTypeDef MPU_InitStruct = {0};

  /* Disables the MPU */
  HAL_MPU_Disable();

  /** Initializes and configures the Region and the memory to be protected
  */
  MPU_InitStruct.Enable = MPU_REGION_ENABLE;
  MPU_InitStruct.Number = MPU_REGION_NUMBER0;
  MPU_InitStruct.BaseAddress = 0x0;
  MPU_InitStruct.Size = MPU_REGION_SIZE_4GB;
  MPU_InitStruct.SubRegionDisable = 0x87;
  MPU_InitStruct.TypeExtField = MPU_TEX_LEVEL0;
  MPU_InitStruct.AccessPermission = MPU_REGION_NO_ACCESS;
  MPU_InitStruct.DisableExec = MPU_INSTRUCTION_ACCESS_DISABLE;
  MPU_InitStruct.IsShareable = MPU_ACCESS_SHAREABLE;
  MPU_InitStruct.IsCacheable = MPU_ACCESS_NOT_CACHEABLE;
  MPU_InitStruct.IsBufferable = MPU_ACCESS_NOT_BUFFERABLE;

  HAL_MPU_ConfigRegion(&MPU_InitStruct);
  /* Enables the MPU */
  HAL_MPU_Enable(MPU_PRIVILEGED_DEFAULT);

}

/**
  * @brief  This function is executed in case of error occurrence.
  * @retval None
  */
void Error_Handler(void)
{
  /* USER CODE BEGIN Error_Handler_Debug */
  /* User can add his own implementation to report the HAL error return state */
  __disable_irq();
  while (1)
  {
  }
  /* USER CODE END Error_Handler_Debug */
}
#ifdef USE_FULL_ASSERT
/**
  * @brief  Reports the name of the source file and the source line number
  *         where the assert_param error has occurred.
  * @param  file: pointer to the source file name
  * @param  line: assert_param error line source number
  * @retval None
  */
void assert_failed(uint8_t *file, uint32_t line)
{
  /* USER CODE BEGIN 6 */
  /* User can add his own implementation to report the file name and line number,
     ex: printf("Wrong parameters value: file %s on line %d\r\n", file, line) */
  /* USER CODE END 6 */
}
#endif /* USE_FULL_ASSERT */

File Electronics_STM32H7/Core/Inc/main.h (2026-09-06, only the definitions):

#define flag_Pin GPIO_PIN_13
#define flag_GPIO_Port GPIOC
#define en_Pin GPIO_PIN_15
#define en_GPIO_Port GPIOC
#define bit3_Pin GPIO_PIN_0
#define bit3_GPIO_Port GPIOA
#define bit2_Pin GPIO_PIN_2
#define bit2_GPIO_Port GPIOA
#define bit1_Pin GPIO_PIN_9
#define bit1_GPIO_Port GPIOE
#define bit0_Pin GPIO_PIN_13
#define bit0_GPIO_Port GPIOE
#define open_Pin GPIO_PIN_9
#define open_GPIO_Port GPIOA
#define close_Pin GPIO_PIN_10
#define close_GPIO_Port GPIOA
#define botton_Pin GPIO_PIN_15
#define botton_GPIO_Port GPIOA

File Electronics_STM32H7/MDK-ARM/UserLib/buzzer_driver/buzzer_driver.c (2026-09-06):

#include "buzzer_driver.h"
#include "tim.h"
#include <math.h>

/* ================================================================
 * 硬件参数（基于 TIM12 当前配置）
 * TIM12 计数器时钟 = 240MHz / 24 = 10MHz
 * PWM 频率 = 10MHz / (ARR + 1)
 * ARR     = 10MHz / freq - 1
 * ================================================================ */
#define BUZZER_TIM           (&htim12)
#define BUZZER_CHANNEL        TIM_CHANNEL_2
#define BUZZER_TIMER_CLK_HZ   10000000UL   /* PSC=24 → 10MHz */
#define BUZZER_ARR_MAX        65535UL

/* ================================================================
 * 音量映射：volume 0~100 → 占空比 0~50%
 * 50% 占空比时基频分量最强，故 volume=100 对应 50% duty
 * ================================================================ */
static void buzzer_set_arr_ccr(uint32_t arr, uint8_t volume)
{
    uint32_t ccr;

    if (volume > 100) volume = 100;

    /* CCR = (ARR+1) * volume / 200   →  volume=100 时占空比=50% */
    ccr = (arr + 1UL) * volume / 200UL;

    __HAL_TIM_SET_AUTORELOAD(BUZZER_TIM, arr);
    __HAL_TIM_SET_COMPARE(BUZZER_TIM, BUZZER_CHANNEL, ccr);

    /* 触发更新事件，立即装载影子寄存器 */
    BUZZER_TIM->Instance->EGR = TIM_EGR_UG;
    (void)BUZZER_TIM->Instance->SR; /* 清除可能挂起的更新标志 */
}

/* ================================================================
 * 公开 API
 * ================================================================ */

/**
 * @brief  按频率和音量播放
 */
void Buzzer_Play(uint16_t freq_hz, uint8_t volume)
{
    uint32_t arr;

    if (freq_hz == 0 || volume == 0) {
        Buzzer_Stop();
        return;
    }

    /* ARR = 计数器时钟 / 频率 - 1 */
    arr = BUZZER_TIMER_CLK_HZ / freq_hz;

    if (arr > 0) {
        arr -= 1;
    }
    if (arr > BUZZER_ARR_MAX) {
        arr = BUZZER_ARR_MAX;   /* 钳位到最低频率 ≈ 153Hz */
    }

    buzzer_set_arr_ccr(arr, volume);
}

/**
 * @brief  按音名 + 八度 + 音量播放
 * @note   基准: A4 = 440Hz
 *         半音距离 = (octave-4)*12 + (note-9)
 *         频率 = 440 * 2^(半音距离/12)
 */
void Buzzer_Note(BuzzerNote_t note, uint8_t octave, uint8_t volume)
{
    float freq;
    int8_t semitones;

    /* 计算目标音与 A4(440Hz) 的半音距离 */
    semitones = (int8_t)(octave - 4) * 12 + ((int8_t)note - (int8_t)BUZZER_NOTE_A);

    /* 频率 = 440 * 2^(semitones/12) */
    freq = 440.0f * powf(2.0f, (float)semitones / 12.0f);

    Buzzer_Play((uint16_t)(freq + 0.5f), volume);
}

/**
 * @brief  停止（占空比清零，IO 输出低电平）
 */
void Buzzer_Stop(void)
{
    __HAL_TIM_SET_COMPARE(BUZZER_TIM, BUZZER_CHANNEL, 0);
    BUZZER_TIM->Instance->EGR = TIM_EGR_UG;
    (void)BUZZER_TIM->Instance->SR;
}

/* ================================================================
 * 音调序列状态机（非阻塞，由外部 50ms Tick 驱动）
 * ================================================================ */
typedef enum {
    BUZZER_SEQ_NONE = 0,
    BUZZER_SEQ_ASCEND,    /* 升调：感应区→迎宾区 */
    BUZZER_SEQ_DESCEND,   /* 降调：迎宾区→感应区 */
} BuzzerSeq_t;

static BuzzerSeq_t buzzer_seq = BUZZER_SEQ_NONE;
static uint8_t     buzzer_step = 0;    /* 当前音符索引 0~3 */
static uint8_t     buzzer_tick = 0;    /* 当前音符已持续的 tick 数 */

/* 音符序列（4 音阶，每音 250ms @50ms/tick，总长 1s） */
static const uint16_t ascend_notes[] = {
    BUZZER_FREQ_C4, BUZZER_FREQ_E4, BUZZER_FREQ_G4, BUZZER_FREQ_C5
};
static const uint16_t descend_notes[] = {
    BUZZER_FREQ_C5, BUZZER_FREQ_G4, BUZZER_FREQ_E4, BUZZER_FREQ_C4
};

#define BUZZER_NOTE_COUNT      4
#define BUZZER_TICKS_PER_NOTE  5    /* 5 × 50ms = 250ms 每音 */
#define BUZZER_SEQ_VOLUME      100

/**
 * @brief  启动音调序列（立即播放第一个音符）
 */
void Buzzer_Seq_Start(uint8_t ascending)
{
    buzzer_seq  = ascending ? BUZZER_SEQ_ASCEND : BUZZER_SEQ_DESCEND;
    buzzer_step = 0;
    buzzer_tick = 0;

    /* 立即播放第一个音符（仅写寄存器，非阻塞） */
    Buzzer_Play(ascending ? ascend_notes[0] : descend_notes[0], BUZZER_SEQ_VOLUME);
}

/**
 * @brief  步进序列状态机（每 50ms 调用一次）
 */
void Buzzer_Seq_Tick(void)
{
    if (buzzer_seq == BUZZER_SEQ_NONE) {
        return;
    }

    buzzer_tick++;
    if (buzzer_tick >= BUZZER_TICKS_PER_NOTE) {
        buzzer_tick = 0;
        buzzer_step++;

        if (buzzer_step >= BUZZER_NOTE_COUNT) {
            /* 序列完成，停止并复位 */
            Buzzer_Stop();
            buzzer_seq = BUZZER_SEQ_NONE;
        } else {
            const uint16_t *notes = (buzzer_seq == BUZZER_SEQ_ASCEND)
                                   ? ascend_notes : descend_notes;
            Buzzer_Play(notes[buzzer_step], BUZZER_SEQ_VOLUME);
        }
    }
}

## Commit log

2026-09-05 初始化仓库
    [c1雷达.SLDPRT, 中心板.SLDPRT, 中心板.STEP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]
2026-09-05 写readme
2026-09-05 完成最终版本readme
2026-09-06 增加stm32电控部分
2026-09-06 完成readme
2026-09-06 完善readme
2026-09-06 完成协议攥写

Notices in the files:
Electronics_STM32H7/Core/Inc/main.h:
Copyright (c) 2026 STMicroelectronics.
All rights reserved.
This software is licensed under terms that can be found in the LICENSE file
